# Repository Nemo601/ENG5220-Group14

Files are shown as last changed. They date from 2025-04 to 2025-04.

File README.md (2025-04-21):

# 🗑️ Intelligent Classification Rubbish Bin (Team 14) 
**_"Smarter Sorting, Cleaner Future"_**

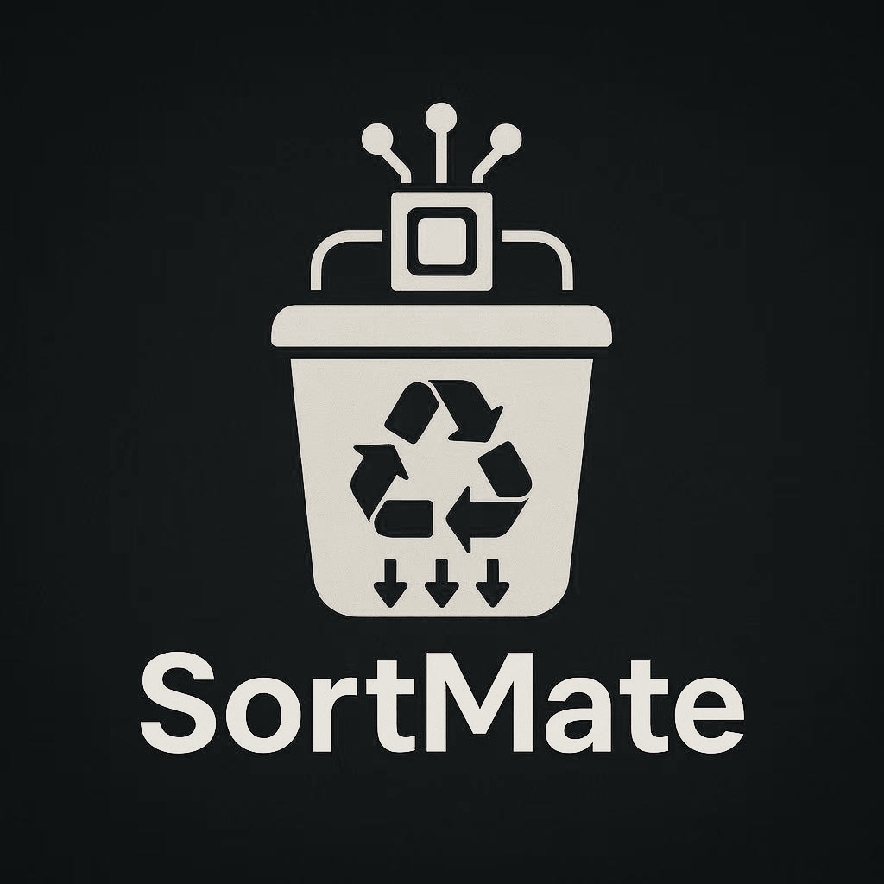
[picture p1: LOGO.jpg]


> Real-time Embedded System | Smart Waste Sorting | Environmental Automation | Raspberry Pi

---

## 📌 Project Overview

The **Intelligent Classification Rubbish Bin** is a real-time embedded system designed for efficient and sustainable waste management. Built on the Raspberry Pi platform, the system integrates computer vision and multi-threaded control to automatically detect and sort waste into the correct bins.

Leveraging **YOLOv5 object detection, stepper motor control**, and **timer-based task scheduling**, this smart bin ensures precise, real-time classification and disposal. The architecture follows **SOLID object-oriented design principles**, enabling high modularity, testability, and scalability—making it ideal for both research and real-world deployment.
This project enhances sustainability by promoting automated recycling, reducing human error, and improving overall waste management efficiency.

**Key Features:**
- **Camera-based waste recognition** using YOLOv5 and NCNN inference framework
- **Real-time multi-threaded scheduling** with timer-triggered callbacks
- **Stepper motor-driven bin rotation system**, offering precise control and extensible logic
- **Modular class structure** based on SOLID principles for easy maintenance and future upgrades
- **Decoupled logic and thread-safe data sharing** through callback interfaces

---

## 📦 Installation

Recommended OS: Raspberry Pi OS (64-bit) / Ubuntu 22.04

Install required dependencies:

```bash
sudo apt-get update
sudo apt-get install -y cmake g++ libopencv-dev wiringpi libjpeg-dev libpng-dev
```

---

## 🔧 Hardware Requirements

### Microcontroller
- Raspberry Pi 5

### Sensors
- 1x PCBA H720P 720P camera module with 2.9mm wide-angle lens (5V, 100mA, 1W, 38dB SNR)
- 1x LM393 H2010 photoelectric infrared sensor (5V, 15.6 x 5.5 x 2.3 cm; 20g)

### Motors & Mechanics
- 4x 28BYJ-48 Geared Stepper Motor (5V, torque >34.3 mN·m, 283g, 14.3 x 8.5 x 3.5 cm)
- 4x Flanged Sleeve Bearings (6.35 mm x 15 mm; inner Ø 6.4 mm, outer Ø 9.3 mm)
- DuPont cable sets

### Structure & Assembly
- Acrylic board sheets (7 types, various sizes; see design spec)
- 4x Acrylic round rods (⌀6 mm x 260 mm)
- 48x Clear acrylic panels (from prior version)
- Handheld hacksaw
- Hot glue gun

---

## ⚙️ System Architecture & Realtime Design

This intelligent waste sorting system is built for **event-driven, real-time embedded control** on Raspberry Pi. It adheres to **modular SOLID design** and minimizes latency through efficient thread management and asynchronous callbacks.

### Real-Time Workflow

```plaintext
      ┌──────────────┐
      │  File Watch  │◄── Raspberry Pi monitors /images directory
      └─────┬────────┘
            │
            ▼
     ┌──────────────┐
     │ CameraWorker │───► Periodically captures images via Timer
     └─────┬────────┘
           │
           ▼
     ┌──────────────┐
     │ YoloDetector │───► Detects objects with YOLOv5 (ncnn) and triggers callback
     └─────┬────────┘
           │
           ▼
     ┌──────────────┐
     │GarbageSorter │───► Classifies object and activates stepper motors
     └──────────────┘
```

---

## 🛠️ Build & Run

### Compile the Project

```bash
cmake .
make
```

### Execute

```bash
./bin/sortmate
```

---

## ⚙️ Software Testing

### Camera & Scheduling Test

- **Modules Tested**: `CameraWorker`, `Timer`
- **Focus**: Periodic capture timing, image integrity
- **Outcome**:
  - Capture duration consistently under **500ms**
  - Interval accuracy within **±100ms** of target 2s cycle
  - No missing or corrupted image files in the watch directory

### YOLOv5 Inference Test

- **Modules Tested**: `YoloDetector`, `NCNN`
- **Focus**: Inference time, callback reliability
- **Outcome**:
  - Average detection time: **<800ms** using lightweight v5lite model
  - Callback triggered correctly for all valid inputs
  - Accurate object counts and label consistency across frames

### Stepper Motor Response Test

- **Modules Tested**: `GarbageSorter`, `StepperMotor`
- **Focus**: Actuation timing, motor-thread safety
- **Outcome**:
  - Total rotation and reset time under **1.5s** per item
  - No threading conflicts or motor blocking observed
  - Detected waste types correctly mapped to motor channels

### Sensor Trigger Test

- **Modules Tested**: GPIO input, `main_sort.cpp` startup logic
- **Focus**: Response latency and reliability
- **Outcome**:
  - System activates within **<500ms** after light sensor trigger
  - No false triggers or missed events in continuous testing
  - State transitions from standby → detection → sorting verified

### Summary

All key real-time functions passed their timing targets with safe margins. The use of **modular class structure, mutexes, and callbacks** ensured stable, thread-safe operation in a resource-constrained embedded environment.

---

## 📣 Social Media & Publicity

Follow us on:

[Instagram](https://www.instagram.com/sortmateteam14?igsh=MXgzd2pqbmxndG1vdA==)

[TikTok](https://www.tiktok.com/@sortmateteam14?_t=ZN-8vYeORF6HlG&_r=1)

Let us know if you'd like to feature or test our prototype!

---

## 👏 Acknowledgements

We would like to thank: 
- **Dr. Bernd Porr** — for his dedicated teaching and continuous project support  
- **Thomas O'Hara** — for his help in preparing project materials  
- **ENG5220 Teaching Team** — for technical guidance and lab assistance  
- **Our peers** — for their collaboration, ideas, and motivation throughout the course

---

## 👥 Team Members

- **Xuan Liu** (3029536L)
- **Yuchen Zhang** (3033100Z)
- **Shiao Hu** (3030874H)
- **Huaqi Liu** (3058895L)
- **Baixiang Kong** (2906728K)

---

## 📮 Contact

📧 Email: kongbx0064@gmail.com

📁 License: MIT

📅 Last Updated: 21/04/2025

---

⭐ If you like this project, give us a star and share with your friends. Let's make waste management smarter together!

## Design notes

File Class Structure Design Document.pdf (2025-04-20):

# Intelligent Waste Sorting System

## Class Structure Design Document

### 1. Overview

This intelligent waste sorting system is designed for embedded platforms like Raspberry Pi. It integrates:

- Image acquisition via camera
- Object detection using YOLOv5
- Task scheduling using timers
- Stepper motor control for physical sorting

The architecture follows SOLID object-oriented design principles, ensuring high maintainability, testability, and scalability.

### 2. SOLID Principles in Practice

Principle | Implementation in the System
SRP – Single Responsibility | Each class is responsible for one task. CameraCapture handles image input only; YoloDetector only detects; GarbageSorter controls sorting logic.
OCP – Open/Closed | System allows extension (e.g., new waste types) without modifying core logic. Motors, image sources, and models are

replaceable.

LSP – Liskov Substitution | StepperMotor can be replaced with a subclass (e.g., servo or virtual motor) without affecting functionality.
ISP – Interface Segregation | Minimal interfaces are exposed (e.g., only captureImage()), reducing unnecessary dependencies.
DIP – Dependency Inversion | High-level logic depends on abstractions (like callbacks), not concrete classes. Detection logic is decoupled from the result processing logic.

### 3. Module Structure & Responsibilities

CameraCapture

- Responsible for capturing images from the camera and saving them.
- Easily replaceable with virtual sources or video feeds.
- Applies: SRP, OCP

CameraWorker

- Combines camera capture with periodic scheduling using a Timer.
- Runs in a background thread.
- Applies: SRP, ISP

YoloDetector

- Encapsulates YOLOv5 model loading and inference using ncnn.
- Provides results asynchronously via callback.
- Applies: SRP, DIP, OCP

GarbageSorter

- Coordinates stepper motors based on detection results.
- Manages system state and sorting logic.
- Applies: SRP, OCP, DIP

StepperMotor

- Controls individual motors via GPIO pins.
- Can be extended or replaced (e.g., with PWM, servo).
- Applies: SRP, LSP

Timer / scheduleTask

- Provides both periodic and delayed task mechanisms.
- Decouples timing from logical operations.
- Applies: SRP, OCP

ThreadController

- Starts/stops the detection process in a managed thread.
- Supports callback for flexible integration.
- Applies: SRP, DIP

shared_data.h

- Thread-safe shared queues for images and detection results.
- Modular communication across producers and consumers.
- Applies: SRP

### 4. Decoupled Design & Interfaces

- Detection results are passed via callback interfaces → no tight coupling to business logic.
- Camera + Timer modules are independently testable and replaceable.
- Motors expose simple rotate() and release() interfaces for precise control.
- Thread lifecycle is abstracted away from logic via ThreadController.
- Shared data structures are synchronized for safe access.

### 5. Extensibility & Maintainability

- Model Upgrade: Swap YOLO versions by changing model paths.
- ➕ More Waste Types: Extend WasteType enum and motor map.
- Alternate Motor Controllers: Replace StepperMotor with subclass.
- UI Integration: System status callback can feed UI / web dashboards.
- ✅ Testing: Each module is testable independently due to clear responsibility.

### 6. Summary

This system showcases a clean, scalable embedded architecture applying real-world SOLID principles.
Its modular and extensible design makes it suitable for:

- Education
- Research Prototypes
- Industrial Sorting Systems

It promotes long-term maintainability and seamless integration of upgrades and hardware changes.

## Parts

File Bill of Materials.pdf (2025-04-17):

Board No. | Length | Breadth | Thicknesses | Quantities
1 | 250 | 150 | 1 | 4
2 | 249 | 149 | 1 | 8
3 | 249 | 249 | 1 | 8
4 | 605 | 290 | 2 | 1
5 | 605 | 550 | 2 | 1
6 | 800 | 290 | 2 | 2
7 | 800 | 605 | 2 | 1
Motor | Quantities | Voltage | Torque | Insulation Resistance | Dimensions
28BYJ-48 | 4 | 5V | >34.3mN.m | >10MΩ (500V) | 14.3 x 8.5 x 3.5cm;283g
Camera | Quantities | Voltage | Amps | Power | signal-to-noise ratio
PCBA_H720P | 1 | 5V | 100mA | 1W | 38dB
Photoelectric Sensor | Quantities | Voltage | Dimensions
LM393 H2010 | 1 | 5V | 15.6 x 5.5 x 2.3cm;20g
Spindle | Quantities | Dimensions | Material
Acrylic Round Rods | 4 | 6mm x 260mm | Plastic
Collar | Quantities | Dimensions | Diameter
Flanged Sleeve Bearings | 4 | 6.35mm x 15mm | 6.4mm 9.3mm

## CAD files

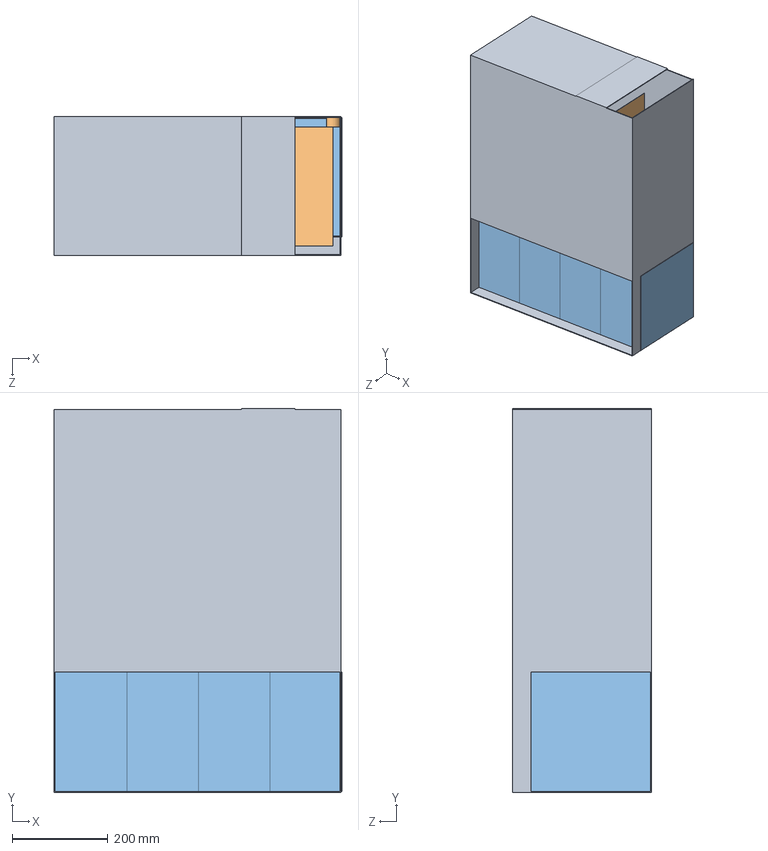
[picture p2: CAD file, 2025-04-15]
3D sketch/Main body.SLDASM
601.9 x 803.8 x 290.0 mm
Sorting lane

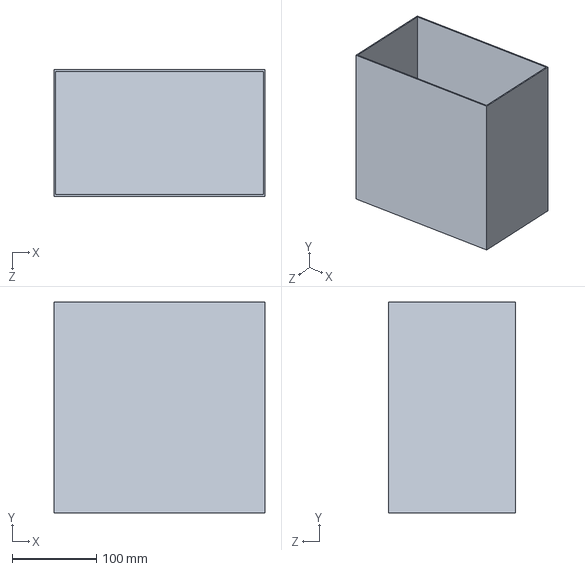
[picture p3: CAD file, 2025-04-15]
3D sketch/Box.SLDPRT
250.0 x 250.0 x 150.0 mm

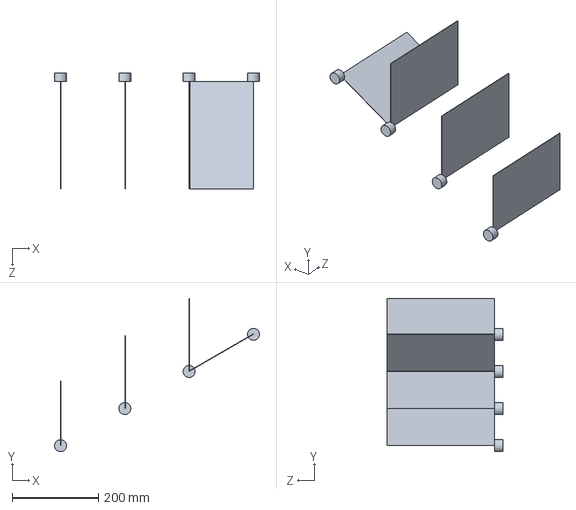
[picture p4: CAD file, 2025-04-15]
3D sketch/Sorting lane.SLDPRT
476.2 x 356.5 x 269.0 mm

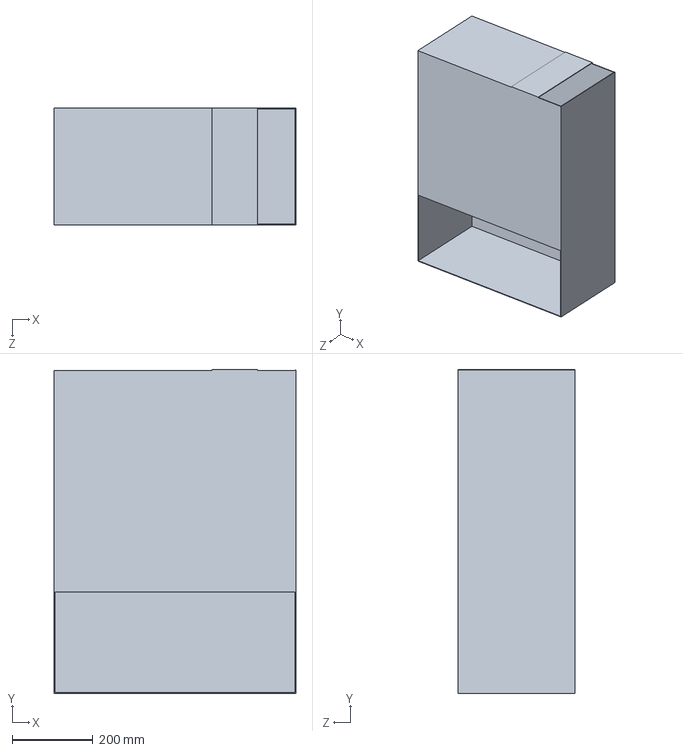
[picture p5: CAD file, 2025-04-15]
3D sketch/Shell.SLDPRT
600.0 x 803.8 x 290.0 mm

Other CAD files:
CAD design sketch/main body sketch.dwg
CAD design sketch/main body shell.dwg
CAD design sketch/Design sketch2.dwg
CAD design sketch/Design sketch1.dwg
CAD design sketch/box.dwg

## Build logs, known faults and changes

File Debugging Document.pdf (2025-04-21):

## Intelligent Waste Sorting System

## Debugging Document

Project Name: Intelligent Classification Rubbish Bin (SortMate)

Platform: Raspberry Pi 5, YOLOv5, Multithreaded C++ Real-Time Control

Objective: Ensure system real-time performance, stability, and inter-module coordination

## Image Capture Time Debugging

### ⚫ Related Modules:

- CameraCapture / CameraWorker
- Timer-based scheduling module

### ⚫ Debugging Objectives:

- Measure the total time from camera activation to image file being saved;
- Verify the accuracy and consistency of the periodic capture cycle (target: one image every
| two seconds);
- Ensure all images are correctly saved to the designated directory, with no corruption or
| loss.
⚫ | Key Checks:
- Capture and save time should remain under 500 ms per image;
- There should be no missing, incomplete, or unreadable image files;
- The time interval between consecutive captures should remain stable, ideally within ±200
| ms of the 2-second target.

### ⚫ Practical Analysis and Recommendations

| During testing, we instrumented the CameraWorker::captureImage() method with time stamps to measure the image acquisition and storage duration. Results show that under stable lighting and proper camera connection, the average time for capturing and saving an image is approximately 220–280 ms, well within the acceptable range. However, we observed that if too many images accumulate in the /home/pi/images/ directory without being cleared, read/write performance may degrade. This issue becomes more pronounced when image capture and image processing threads run in parallel. To address this, we recommend:
- Regularly moving or archiving processed images (e.g., to a /processed/ folder);
- Using timestamp-based filenames to avoid naming collisions;
- Implementing a timeout or “capture skip” mechanism in the Timer logic to prevent
| overlapping operations if the previous frame has not finished processing. To further evaluate the stability of the capture interval, we suggest logging timestamps of consecutive captures and plotting them as a line chart to identify timing drift or frame drops.

## YOLO Processing Time Debugging

### ⚫ Related Modules:

- YoloDetector
- NCNN inference engine pipeline

### ⚫ Debugging Objectives:

- Measure the total duration from image loading to YOLO inference completion;
- Evaluate whether the YOLO model constitutes a bottleneck in real-time performance;
| -Verify that the detection callback is triggered correctly and the results are accurate.
⚫ | Key Checks:
- Inference time should be within 800 ms;
- The callback is invoked correctly with accurate object counts;
- If using a lightweight model (e.g., v5lite), assess trade-offs between speed and accuracy.

### ⚫ Practical Analysis and Recommendations

| To evaluate YOLO performance, we recorded timestamps at the entry and exit points of the YoloDetector::Impl::detect() function. Across multiple test images, we observed an average inference time of approximately 420 ms using the v5lite model, providing relatively smooth system response. However, when using higher-resolution images or under high thread concurrency, the inference time can spike to over 700 ms, which may negatively impact the timing of motor operations. In response, we recommend the following: For stricter real-time constraints, consider using an even smaller model like v5nano; Enable NCNN’s Vulkan acceleration or switch to OpenVINO for improved inference speed; Normalize input image sizes (e.g., resize to 320×320) to reduce dynamic memory overhead; Ensure that the callback function is not blocked by the main thread or downstream processes—consider adding asynchronous protection mechanisms if necessary. Additionally, we recommend logging detection metadata, such as the number of objects per frame, label distribution, and confidence scores. This data is helpful for post-deployment analysis of model consistency and accuracy.

## Stepper Motor Rotation Time Debugging

### ⚫ Related Modules:

- GarbageSorter
- StepperMotor

### ⚫ Debugging Objectives:

- Log the total duration of each motor classification task;
- Analyze response timing and reset behavior;
- Ensure the delay-return (managed by the timer) is precise and consistent.

### ⚫ Key Checks:

- Motor action should complete within 1.5 seconds;
- No thread conflicts or motor contention;
- Detected waste type matches the motor movement.

### ⚫ Practical Analysis and Recommendations

| The system uses the GarbageSorter::processWaste() function to activate different stepper motors based on the classification label provided by YOLO. In our tests, we instrumented the function with entry and exit timestamps to calculate the time taken for each classification action. Test Results: 1.The average duration for a single motor action ranged between 900–1200 ms, which meets the performance target; 2.The timer-managed reset mechanism was generally consistent. However, under high- frequency detection or rapid image capture, we observed a race condition where a motor could be reactivated before it had fully returned to its idle state. To ensure stable and predictable behavior, we recommend the following improvements: 1.Sequential Execution Queue: Introduce a motor task queue to ensure classification actions are processed one at a time; 2.Motor Busy Flags: Implement internal state flags within the StepperMotor class to prevent new actions before the previous one completes; 3.Timeout-Protected Resets: Use scheduleTask to enforce a maximum safe return time for each motor reset; 4.GPIO Monitoring: Log or programmatically check the GPIO usage status to detect any hardware-level conflicts or failures. Additionally, it is advisable to log every motor classification event with associated details such as object label, motor ID, and execution time. This data can be used to evaluate system load, categorize waste statistics, and further optimize the motor control logic.

## Sensor Response Time Debugging

### ⚫ Related Modules:

- Phototransistor (light sensor) input (GPIO)
- System initialization logic in main_sort.cpp

### ⚫ Debugging Objectives:

- Measure response time between sensor trigger and system startup;
- Detect and avoid false positives or missed triggers;
- Confirm system transitions correctly from "standby" to "active" mode.

### ⚫ Key Checks:

- Response time should be within 500 ms;
- Sensor connection is stable, with minimal jitter;
- System correctly starts the image capture and detection process after trigger.

### ⚫ Practical Analysis and Recommendations

The system monitors the GPIO pin connected to the phototransistor to detect nearby waste. Upon detection, the main control thread initiates the capture and classification sequence. In our practical tests, the response time from GPIO signal detection to system activation averaged between 150 ms and 250 ms, which meets performance expectations.
However, several edge cases were observed:
1.Signal bouncing or poor wiring could cause multiple false triggers or unstable states, leading to unexpected system behavior;
2.Ambient lighting conditions, such as strong sunlight, may interfere with sensor accuracy and require shielding or a sensor upgrade;
3.When digitalRead() is polled too infrequently (e.g., >200 ms intervals), short trigger signals may be missed entirely.
To improve reliability and robustness, we recommend:
1.Increase polling frequency: Reduce sleep_for() duration in the main loop from 100 ms to 30–50 ms;
2.Debounce logic: Add a short delay (e.g., 50 ms) after detection to confirm signal stability;
3.Logging mechanism: Log timestamped trigger events and response status to analyze potential misfires or unresponsive behavior;
4.Hardware-level improvements: Use RC filters or switch to digital infrared proximity sensors with built-in noise suppression.
The sensor acts as the entry point to the entire classification workflow. Its responsiveness and reliability directly affect downstream modules. We therefore suggest treating sensor behavior as a critical real-time test item and incorporating its metrics into formal system evaluation.

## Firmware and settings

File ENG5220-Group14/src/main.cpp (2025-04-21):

#include "../include/yolo_detector.h"
#include "../include/GarbageSorter.h"
#include "../include/Timer.h"
#include <opencv2/highgui.hpp>
#include <opencv2/imgproc.hpp>
#include <opencv2/videoio.hpp>
#include <filesystem>
#include <iostream>
#include <atomic>
#include <csignal>
#include <wiringPi.h>
#include <thread>
#include <mutex>
#include <unordered_map>
#include "../include/CameraWorker.h"

std::atomic<bool> running(true);
std::shared_ptr<std::vector<Object>> latest_result;
std::mutex latest_mutex;
namespace fs = std::filesystem;

bool image_exists = false;

void signalHandler(int) {
    running = false;
    std::cout << "\n[System] Exit signal received (Ctrl+C), ready to exit...\n";
}

bool hasImageInDirectory(const std::string& path) {
    for (const auto& entry : fs::directory_iterator(path)) {
        if (entry.is_regular_file()) {
            std::string ext = entry.path().extension().string();
            if (ext == ".jpg" || ext == ".png" || ext == ".jpeg" || ext == ".bmp") {
                return true;
            }
        }
    }
    return false;
}

int main() {
    const std::string watch_path = "/home/pi/ENG5220/image";
    std::unordered_map<int, int> label_to_category = {
        {0, 3}, {1, 3}, {2, 3}, {3, 3}, {4, 3}, {5, 3}, {6, 3}, {7, 3}, {8, 3}, {9, 1},
        {10, 1}, {11, 1}, {12, 1}, {13, 1}, {14, 3}, {15, 3}, {16, 3}, {17, 3}, {18, 3}, {19, 3},
        {20, 3}, {21, 3}, {22, 3}, {23, 3}, {24, 1}, {25, 1}, {26, 1}, {27, 1}, {28, 1}, {29, 1},
        {30, 1}, {31, 1}, {32, 1}, {33, 1}, {34, 1}, {35, 1}, {36, 1}, {37, 1}, {38, 1}, {39, 1},
        {40, 1}, {41, 1}, {42, 1}, {43, 1}, {44, 1}, {45, 1}, {46, 2}, {47, 2}, {48, 2}, {49, 2},
        {50, 2}, {51, 2}, {52, 2}, {53, 2}, {54, 2}, {55, 2}, {56, 1}, {57, 1}, {58, 3}, {59, 1},
        {60, 1}, {61, 4}, {62, 1}, {63, 1}, {64, 4}, {65, 4}, {66, 4}, {67, 1}, {68, 1}, {69, 1},
        {70, 1}, {71, 1}, {72, 1}, {73, 4}, {74, 1}, {75, 4}, {76, 4}, {77, 4}, {78, 4}, {79, 4}
    };

    wiringPiSetupGpio();
    const int SENSOR_PIN = 25;
    pinMode(SENSOR_PIN, INPUT);
    pullUpDnControl(SENSOR_PIN, PUD_UP);
    signal(SIGINT, signalHandler);

    std::cout << "Waiting for the photoelectric sensor to trigger..." << std::endl;
    while (digitalRead(SENSOR_PIN) == HIGH && running) {
        std::this_thread::yield();
    }
    if (!running) {
        std::cout << "Interrupted before startup, exit.\n";
        return 0;
    }
    std::cout << "Object detected, system activated！" << std::endl;

    CameraWorker cw;
    cw.start();
    startTimerThread();
    signal(SIGINT, signalHandler);  // Re-register

    std::vector<std::vector<int>> motorPins = {
        {4, 17, 23, 24}, {5, 6, 12, 13}, {16, 20, 21, 26}, {18, 19, 22, 27}
    };
    GarbageSorter sorter(motorPins);
    sorter.setStatusCallback([](const std::string& msg) {
        std::cout << "[system status] " << msg << std::endl;
    });
    sorter.startSystem();

    YoloDetector detector;
    if (!detector.loadModel("/home/pi/ENG5220/weights/yolov5s_6.0.param", "/home/pi/ENG5220/weights/yolov5s_6.0.bin")) {
        std::cerr << "Model loading failure." << std::endl;
        return -1;
    }

    detector.setCallback([](const std::vector<Object>& objs) {
        std::lock_guard<std::mutex> lock(latest_mutex);
        latest_result = std::make_shared<std::vector<Object>>(objs);
        std::cout << "detected " << objs.size() << " target。" << std::endl;
    });

    // Timing check pictures
    IntervalTimer checkImageTimer;
    checkImageTimer.setInterval([&]() {
        bool now_has_image = hasImageInDirectory(watch_path);

        if (now_has_image && !image_exists) {
            std::cout << "[Event] A new image is detected and the recognition thread is started." << std::endl;
            std::thread detect_thread([&detector, &watch_path]() {
                for (const auto& entry : fs::directory_iterator(watch_path)) {
                    std::string ext = entry.path().extension().string();
                    if (ext == ".jpg" || ext == ".png" || ext == ".jpeg" || ext == ".bmp") {
                        cv::Mat img = cv::imread(entry.path().string());
                        if (!img.empty()) {
                            detector.detect(img);
                            fs::remove(entry.path());
                        }
                    }
                }
            });
            detect_thread.detach();
        }

        if (!now_has_image && image_exists) {
            std::cout << "[Event] Catalogue has no pictures, terminating the recognition behaviour." << std::endl;
        }

        image_exists = now_has_image;

        std::shared_ptr<std::vector<Object>> local_copy;
        {
            std::lock_guard<std::mutex> lock(latest_mutex);
            if (latest_result && !latest_result->empty()) {
                local_copy = latest_result;
                latest_result.reset();  // ⚠️ Clearance to avoid duplication of processing
            }
        }

        if (local_copy) {
            std::thread motor_thread([local_copy, &sorter, &label_to_category]() {
                for (const auto& obj : *local_copy) {
                    int label = obj.label;
                    auto it = label_to_category.find(label);
                    if (it != label_to_category.end()) {
                        int category = it->second;
                        std::cout << "Target number " << label << " Match classification: " << category << std::endl;
                        sorter.processWaste(static_cast<GarbageSorter::WasteType>(category));
                        sorter.waitUntilIdle();
                    } else {
                        std::cout << "Warning: undefined label number " << label << "，Skip that target." << std::endl;
                    }
                }
                std::cout << "The motor action is complete and the thread exits." << std::endl;
            });
            motor_thread.detach();
        }
    }, 500); // Check every 500ms

    // Non-blocking main thread polling
    std::cout << "The system is running...(main thread non-blocking)" << std::endl;
    while (running) {
        std::this_thread::yield();  // Non-blocking, giving up CPU
    }

    // Stop System
    checkImageTimer.stop();
    cw.stop();
    sorter.stopSystem();
    stopTimerThread();

    std::cout << "The system has been safely exited." << std::endl;
    return 0;
}

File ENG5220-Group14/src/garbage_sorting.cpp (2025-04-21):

#include <iostream>
#include <string>
#include <atomic>
#include <thread>
#include <chrono>
#include <wiringPi.h>
#include "StepperMotor.h"
#include "Timer.h"

using namespace std;

int main() {
    wiringPiSetupGpio();

    StepperMotor motor1({4, 17, 23, 24});
    StepperMotor motor2({5, 6, 12, 13});
    StepperMotor motor3({16, 20, 21, 26});
    StepperMotor motor4({18, 19, 22, 27});

    startTimerThread(); // Starting a timed task thread

    atomic<bool> isBusy(false);
    string input;

    cout << " Rubbish sorting system activated. Please enter recognition result (1~4 or q):" << endl;

    while (true) {
        // Wait for the current task to complete before allowing input
        while (isBusy.load()) {
            this_thread::sleep_for(chrono::milliseconds(100));
        }

        cout << "\nEnter the recognition result (1 to 4 or q): ";
        cin >> input;

        if (input == "q") break;

        isBusy.store(true); // Setting Busy Status

        if (input == "1") {
            cout << " Recyclable waste disposal" << endl;
            motor1.rotate(500, true);
            motor2.rotate(500, true);

            scheduleTask(1, [&]() {
                motor1.rotate(500, false);
                motor2.rotate(500, false);
                cout << " Recyclable withdrawal completed" << endl;
                isBusy.store(false);
            });
        }
        else if (input == "2") {
            cout << " Organic waste disposal" << endl;
            motor2.rotate(1000, true);

            scheduleTask(1, [&]() {
                motor2.rotate(1000, false);
                cout << " Organic withdrawal completed" << endl;
                isBusy.store(false);
            });
        }
        else if (input == "3") {
            cout << " Hazardous waste disposal" << endl;
            motor1.rotate(100, true);

            scheduleTask(1, [&]() {
                motor1.rotate(100, false);
                cout << "Hazardous withdrawal completed" << endl;
                isBusy.store(false);
            });
        }
        else if (input == "4") {
            cout << " Other waste disposal" << endl;
            motor4.rotate(100, true);

            scheduleTask(1, [&]() {
                motor4.rotate(100, false);
                cout << " Other withdrawal completed" << endl;
                isBusy.store(false);
            });
        }
        else {
            cout << " Invalid input. Please enter 1 to 4 or q." << endl;
            isBusy.store(false);
        }
    }

    stopTimerThread(); // Stopping the timer thread
    cout << " System exited." << endl;
    return 0;
}

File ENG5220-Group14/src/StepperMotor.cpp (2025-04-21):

#include "StepperMotor.h"
#include <wiringPi.h>
#include <unistd.h>

const int StepperMotor::sequence[8][4] = {
    {1, 0, 0, 0}, {1, 1, 0, 0}, {0, 1, 0, 0}, {0, 1, 1, 0},
    {0, 0, 1, 0}, {0, 0, 1, 1}, {0, 0, 0, 1}, {1, 0, 0, 1}
};

StepperMotor::StepperMotor(const std::vector<int>& gpioPins) : pins(gpioPins) {
    for (int pin : pins) {
        pinMode(pin, OUTPUT);
        digitalWrite(pin, LOW);
    }
}

void StepperMotor::rotate(int steps, bool clockwise, int delayMs) {
    for (int i = 0; i < steps; ++i) {
        int idx = clockwise ? i % 8 : 7 - (i % 8);
        for (int j = 0; j < 4; ++j) {
            digitalWrite(pins[j], sequence[idx][j]);
        }
        usleep(delayMs * 1000);
    }
    release();
}

void StepperMotor::release() {
    for (int pin : pins) {
        digitalWrite(pin, LOW);
    }
}
